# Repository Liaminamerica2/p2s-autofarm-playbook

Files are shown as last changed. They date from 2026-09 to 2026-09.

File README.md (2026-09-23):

# p2s-autofarm

**A self-hosted, hands-off print farm for the Bambu Lab P2S: queueing, server-side slicing, and automatic part ejection, all on your LAN with no cloud required.**

Free to use, fork, and build on for individuals, hobbyists, and small shops (see [License](#license)).

> **Unofficial community guide.** Not affiliated with or endorsed by Bambu Lab, 3D Farmers, or the Bambuddy project. All product names are trademarks of their owners. Anything that moves the toolhead or bends the build plate can damage your printer. Test every change slowly while watching the machine, and use this guide at your own risk.

> **DRAFT:** items marked **TODO** need your own photos, measurements, or a status check before publishing.

---

## What this is

A working setup (and a list of the gotchas) for running a Bambu Lab P2S as an unattended print farm:

- **Bambuddy** for queueing, archiving and print management, self-hosted in Docker
- **Slicer sidecars** (OrcaSlicer and Bambu Studio APIs) for slicing on the server
- **FarmLoop Stage 2** hardware for automatic door opening and plate bending to eject finished parts
- **Everything over local network**: LAN-only mode, Developer Mode, local MQTT

Built and tested on a P2S with AMS 2 Pro. Much of it should carry over to other Bambu printers, but the P2S has quirks (see [Troubleshooting](#troubleshooting)).

## Tested with

| Component | Version |
|---|---|
| Printer | Bambu Lab P2S + AMS 2 Pro |
| Bambuddy | 1.2.5.5 |
| FarmBoard firmware | 2.94 |
| FarmLoop app | 2.72 (states it is tested up to Bambu Studio 2.6) |
| Server | Ubuntu, x86_64, headless, Docker Compose |

> **TODO:** update these to whatever you're running when you publish.

## Architecture

```mermaid
flowchart LR
  D["Desktop slicer<br/>OrcaSlicer / Bambu Studio"] -->|.3mf files| B["Bambuddy<br/>(Docker, port 8001)"]
  B -->|slice requests| S["Sidecars<br/>orca-slicer-api :3003<br/>bambu-studio-api :3001"]
  B -->|LAN mode| P["Bambu P2S"]
  F["FarmBoard<br/>(ESP32-S3)"] -->|watches local MQTT| P
  F -->|drives| M["Door + plate bender"]
```

The FarmBoard does **not** run on custom G-code alone. It connects to the printer's local MQTT broker, watches print progress, and fires its own door and bender motors when it sees timing markers that were embedded in the print file. That is why LAN-only mode and Developer Mode are required, and why processed files must not be renamed or re-saved.

## What's running today

Bambuddy and the OrcaSlicer sidecar are live on a headless Ubuntu box, queueing and archiving prints sent from OrcaSlicer over the LAN. The FarmLoop Stage 2 board is wired into the printer's local MQTT and handles door/bender ejection (bender is unused as it props open the bottom of the p2s printer so i took it out and I just use an engineering plate which releases bellow 30°C) on `FL_S2_`-processed files. The Bambu Studio sidecar and full end-to-end ejection timing are still being confirmed — see [status and troubleshooting](troubleshooting/README.md) if you're building this yourself and want the details.

## Guide contents

For people who want to build this themselves — the full setup, in the order you'd actually do it:

1. **[hardware-setup/](hardware-setup/README.md)** — printer network prep, FarmLoop Stage 2 board assembly, and part-detachment/ejection tuning.
2. **[software-setup/](software-setup/README.md)** — Bambuddy, the slicer sidecars, and the desktop slicer.
3. **[gcode-snippets/](gcode-snippets/README.md)** — known-good G-code fixes injected into prints for the ejection cycle.
4. **[air-quality-and-ventilation/](air-quality-and-ventilation/README.md)** — keeping fumes and particulates out of the room while the farm runs unattended.
5. **[troubleshooting/](troubleshooting/README.md)** — symptom/fix table and the detailed per-component status, for when something doesn't work.

## Alternatives

- **SimplyPrint** offers a FarmLoop AutoPrint integration, but it moved behind its paid Pro plan after its free beta.
- **FarmLoop Pro app** does not work as intended. See [FL_S2_INCIDENT.md](FL_S2_INCIDENT.md).

## Keep out of your fork or PR

Never commit your LAN access code, printer serial number, real IP addresses or Wi-Fi credentials. Also leave out vendor firmware binaries and app-generated files. Use placeholders such as `<PRINTER_IP>` and `<ACCESS_CODE>` in anything you share.

## Contributing

Corrections and other-printer notes are welcome. Open an issue or PR with the printer model, firmware version and what you tested.

## License

[Polyform Small Business License 1.0.0](LICENSE) — free to use, modify, and redistribute (including commercially) for individuals, nonprofits, and small businesses. Larger companies should contact the maintainer about separate terms rather than assume the free grant applies.

## Credits

- [Bambuddy](https://github.com/maziggy/bambuddy) by maziggy -- what a framework!
- 3D Farmers (FarmLoop) documentation and community
- Claude

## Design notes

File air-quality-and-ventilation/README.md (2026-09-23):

# Air quality & ventilation

Keeping print fumes and particulates from ending up in the room while the farm runs unattended.

## Optional: ventilation and placement

- The P2S recirculates air through its built-in HEPA and carbon filter and does **not** vent outside by default.
- Bambu sells an **External Exhaust Fan Kit** (about $20). It needs printer firmware 01.01.01.00 or newer, Bambu Studio 2.4.1.80 or newer, and Bambu Handy 3.11.0 or newer. Ducting and a window adapter are extra, roughly $30 to $50 (4" duct, window panel or foam-board insert, louvered outdoor cap).
- Newer P2S units ship with an updated rear panel that has proper exhaust cutouts. Owners of the original panel could request one.
- **Avoid open-air spaces** like a patio or cabana: temperature swings, dew, dust in the AMS and fans, and filament absorbing moisture.
- Stick to PLA and PETG if the printer lives in a bedroom. Vent ABS and ASA outside.

> **TODO:** add photos of the exhaust kit install, duct routing, and window adapter once installed.

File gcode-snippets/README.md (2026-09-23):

# G-code snippets

Known-good G-code fixes for Bambuddy's per-model start/end G-code injection (**Settings → Workflow → G-code Injection → P2S**), used to keep the FarmLoop Stage 2 board's ejection cycle in sync with the print. See [../software-setup/README.md#4-wire-it-into-bambuddy](../software-setup/README.md#4-wire-it-into-bambuddy) for where this gets configured, and [../hardware-setup/README.md](../hardware-setup/README.md) for the mechanism these markers drive.

> **TODO:** drop your actual working injection files in this folder (e.g. `end-gcode-p2s.gcode`) once finalized, and list them below. The notes here are what's been learned so far — the vendor tools regenerate raw G-code that needs the same fixes reapplied each time.

See **[GCODE-HOWTO.md](GCODE-HOWTO.md)** for the reverse-engineered mechanism behind the FarmBoard trigger sequence (MQTT sentinels via `M104 Sn`, tap/press gestures, sweep and cooldown blocks) — read this before hand-writing an injection block instead of relying on the FarmLoop app's output.

## Known-good notes

- On the P2S, `M106 P2` is the **auxiliary** fan and `M106 P3` is the **exhaust** fan. Generated code that fires the wrong one for cooldown needs `P2` swapped for `P3` in both the on and off lines.
- The stock Machine End G-code already runs a two-stage cooldown (aux fan first, then an exhaust fan gated on chamber temperature) **before** any block you add. If the door seems to wait forever, look there first — it's usually not your injected block.
- If the sweep or push runs too high and misses parts, measure the vertical gap between the nozzle tip and the pusher's contact face with the printer idle. Generated math may assume they're coplanar.
- Bambuddy inserts your start snippet **after** the printer's own homing/heat/prime, and your end snippet **after** the printer's entire stock end sequence (which ends in `M18`, steppers off). So: no `G28` needed at the top of a start snippet, and an `M17` is needed at the top of an end snippet before any `G1 Z` move. See [GCODE-HOWTO.md §10](GCODE-HOWTO.md#10-how-bambuddy-actually-inserts-these-snippets) for the full mechanism, verified against Bambuddy source.
- Injection failure is silent — a bad snippet just falls back to the un-injected file with a server-side log line, nothing visible on the printer.

## Files in this folder

- **[`start-gcode-p2s.gcode`](start-gcode-p2s.gcode)** — start-of-print injection: homes, then arms the FarmBoard (RESET sentinel + 4-tap gesture) and fires TRIGGER 0.
- **[`end-gcode-p2s.gcode`](end-gcode-p2s.gcode)** — end-of-print injection ("Option A" in [GCODE-HOWTO.md §9](GCODE-HOWTO.md#9-options-for-the-ejection-block)): cools with the door closed, gates the door open on bed temperature, sweeps the plate with the pusher, closes the door. Bender/safety stages are skipped — that hardware isn't in this build.
- **The test plan** — the header of `end-gcode-p2s.gcode` is an 8-step, one-variable-at-a-time campaign (cooling → plate release / is the bender needed → door → pusher height on an empty plate → sweep on a real part → full cycle → the print after → first unattended run), each step naming the parameter it fills in. Test snippets for the steps that are easy to get wrong by hand:
  - [`end-gcode-test-door.gcode`](end-gcode-test-door.gcode) — step 3: open, wait, close; nothing else.
  - [`end-gcode-test-sweep-height.gcode`](end-gcode-test-sweep-height.gcode) — step 4b/4c: one sweep at a fixed height on an empty plate, run per height from Z20 down; finds `SWEEP_MIN` without ever using the placeholder.
- **[`end-gcode-test-m190.gcode`](end-gcode-test-m190.gcode)** — step 1, diagnostic only. Swap it in for one run to learn whether `M190 S28` really blocks until the bed cools; the readout is the part fan spinning up and a 30 mm toolhead jog after each wait, plus the bed temperature when Finished appears (no door, no taps, no FarmBoard involved — and no "logo lamp", the P2S doesn't have one). Procedure and result table in [GCODE-HOWTO.md §11](GCODE-HOWTO.md#11-first-live-run-2026-09-20-and-the-m190-test). **Do not use `M190 R` on this printer** — it raised a bed-over-limit error and clamped the bed target up.
- The tunable values (release temperature, dwell padding, the `{max_layer_z} − 10` sweep height and its 12 mm minimum) are in the comment header at the top of `end-gcode-p2s.gcode` — read that before your first run.

**Status (2026-09-22):** every non-stock line in both snippets has been checked against the P2S stock templates, the community G-code atlas, the FarmLoop vendor docs and forum reports — the table is [GCODE-HOWTO.md §12](GCODE-HOWTO.md#12-line-by-line-verification-2026-09-22). Door open/close and the sentinels work on this board; the sweep height is per-model; cooldown now recirculates through the filter instead of venting. Still unconfirmed on this printer: the `M190 S` finish temperature (test snippet running), pusher contact at the new sweep height, and how long filter-mode cooldown takes.

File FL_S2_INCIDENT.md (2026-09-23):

# Incident report: the FarmLoop Pro app's G-code idles a hot printer for hours

**TLDR:** I bought the FarmLoop Stage 2 kit for hands-off printing on my Bambu Lab P2S. The G-code the FarmLoop Pro app (v2.72) produced for me contains a two-hour "natural cooldown" wait in the **start** of every loop, before the print begins, with the heaters on and the fans off. I saw it on two different models. On the first, the printer stalled and I ran it for about 30 minutes before cutting power.

This repo exists because software sold for *unattended* printing has to produce G-code that is safe when nobody is watching, and I could not rely on that.

> **DRAFT:** items marked **TODO** need your own confirmation, screenshots or files before publishing.

---

## What I am and am not claiming

**Claiming (verified from the files):**

- The processed files contain the block shown below, in the start sequence, once per loop.
- The block's own comment says it is meant to run before the door opens, which is post-print logic.
- The heaters are left on and the fans are switched off while it runs.
- This is what the app gave me on two different models. 

**Not claiming:**

- That the vendor intended this, or knew about it.
- That every file, printer model or app version has the problem. I only tested a P2S with app v2.72.
- That my printer was permanently damaged.

The app itself tells users they use it at their own risk. This report is about what that risk looked like in practice.

---

## Timeline

Dates are approximate.

| When | What happened |
|---|---|
| Aug 2026 | Bought and installed the FarmLoop Stage 2 hardware for the P2S. |
| Sep 6 | Ran the first processed file (File A). About 5 minutes in, after the AMS filament step, the printer stopped making progress. I let it run about 30 minutes, then cut power and inspected the machine. |
| Sep 7–8 | Unzipped File A and a plain slice of the same model and diffed them. Found the cooldown block. |
| Sep 19 | Processed a new, unrelated model (File B) in the app. **The same block is present.** I did not run it. |

---

## This is the app's default output

Both files came straight out of the app's **Process Gcode** step. I did not edit them, rename them or re-save them in a slicer.

Settings visible in File B's G-code:

| Setting | Value in the file |
|---|---|
| Printer | P2S |
| Detachment | Push Mode (the only mode available on the P2S) |
| Loops | 2 |
| Bed temperature | 55 °C |
| Post-print cooldown | Temperature-based, target 26 °C |

Screenshots of the **Detachment Tuning** page for File B, taken before clicking Process Gcode, confirm these match what was on screen — Push Mode, 55 °C bed, and a temperature-based cooldown targeting 26 °C:

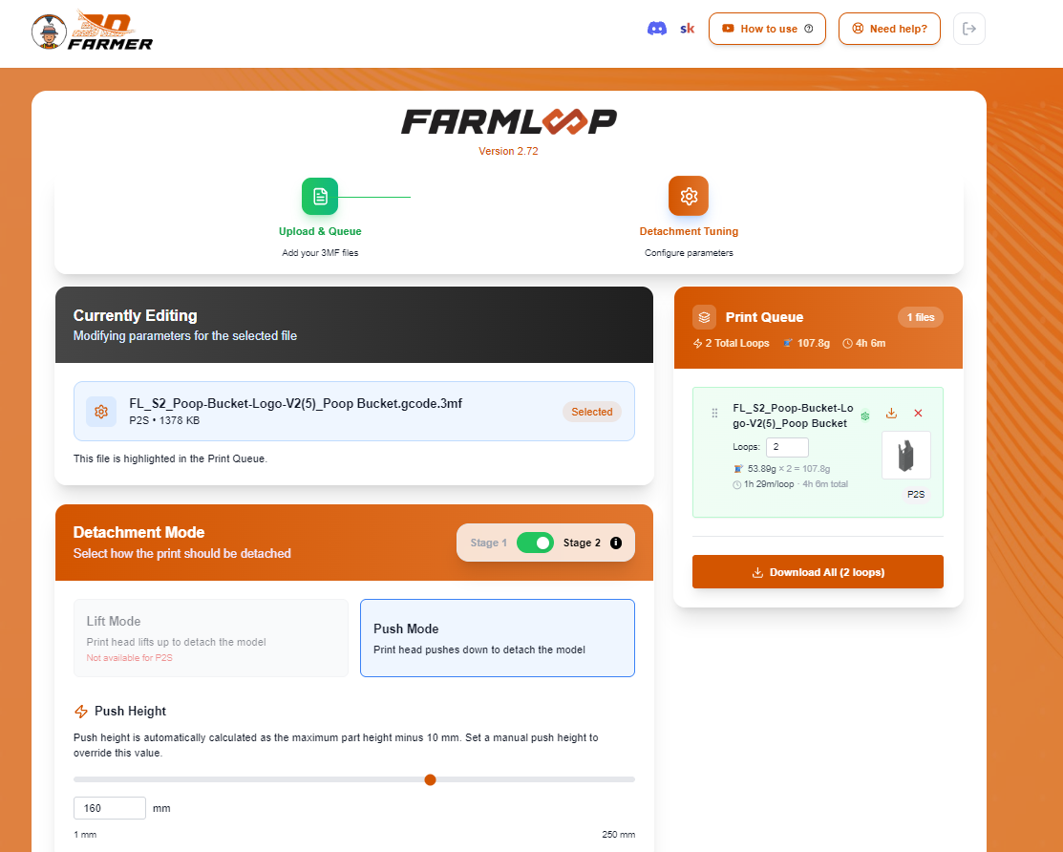
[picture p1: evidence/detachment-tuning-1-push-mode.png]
Detachment Mode and Push Height settings in the FarmLoop app


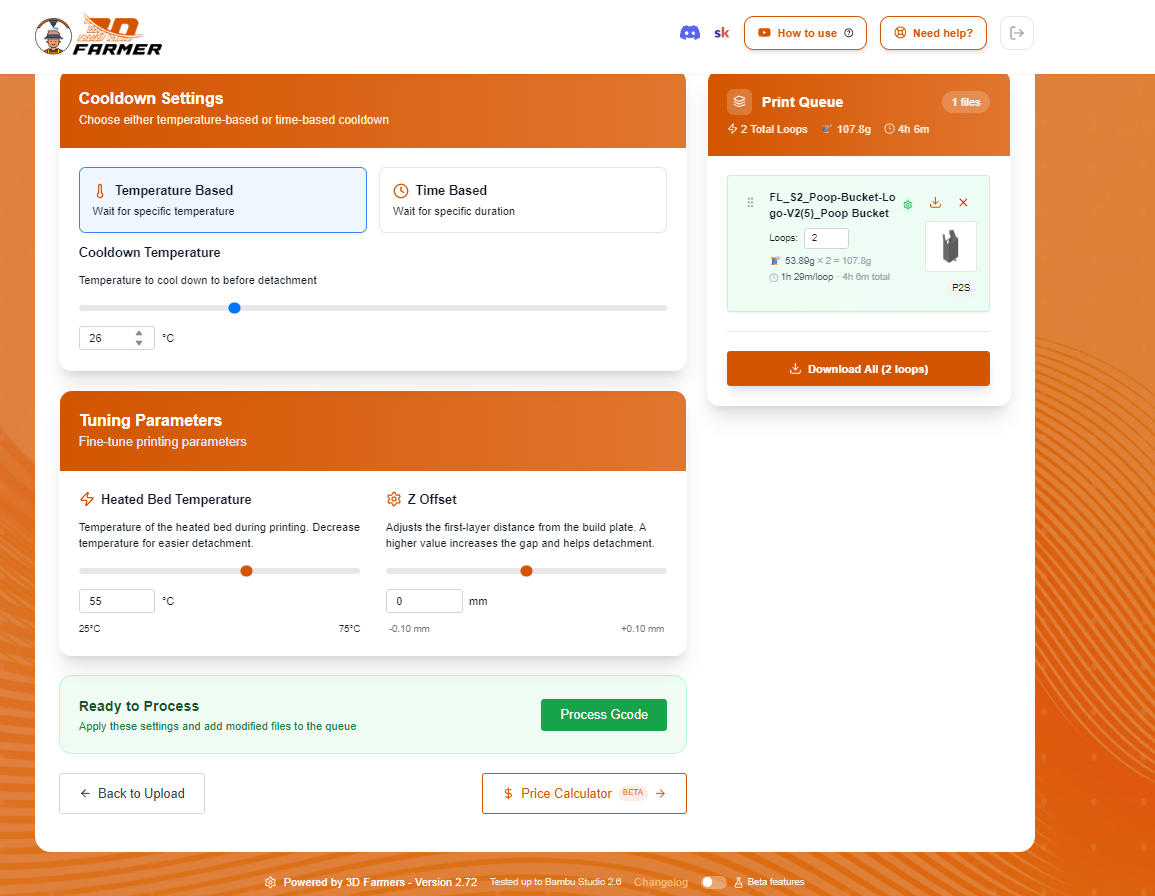
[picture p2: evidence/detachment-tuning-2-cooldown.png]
Cooldown Settings and Tuning Parameters in the FarmLoop app


**Beta features were off** (see the toggle in the app's footer, bottom right of the second screenshot). Nothing here came from an experimental or opt-in feature — Push Mode, temperature-based cooldown, and the bed/Z-offset tuning are all part of the app's regular, out-of-beta feature set. This is the G-code the app's stable, promised functionality produces.

---

## What the G-code does

Excerpt from the processed file. The repeated dwell lines are elided:

```gcode
; ================ FL NATURAL COOLDOWN ================
; Hold in the closed chamber for 120 min before the door opens.
; Fans off so the part cools evenly instead of from one side — ASA, ABS
; and PC warp and split when cooled fast while still stuck to the plate.
M106 S0          ; part cooling fan off
M106 P2 S0       ; auxiliary fan off
M106 P3 S0       ; chamber fan off
G4 S30
G4 S30
... (240 x G4 S30 in total)
; ================ FL NATURAL COOLDOWN END (120 min) ================
M104 S220
```

`G4 S30` is a 30-second dwell. 240 of them is 7,200 seconds, or 2 hours.

| | File A | File B |
|---|---|---|
| Loops | 2 | 2 |
| Dwells per loop | 240 x `G4 S30` (2 h) | 240 x `G4 S30` (2 h) |
| Total wait before printing | About 4 h | About 4 h |
| Fans during the wait | Off | Off |
| What follows the block | `M104 S220` (heat to print temperature) | `M104 S220` |

### Why this is a defect

1. **It is in the wrong place.** The comment describes a post-print hold ("before the door opens"), but the block runs before printing starts.
2. **The heaters stay on.** In File B, the start sequence sets the bed to 55 °C and holds the nozzle at a 140 °C target before the block. There is no heater-off command between those lines and the end of the block, so both stay on for the full two hours. The nozzle only goes to 220 °C afterwards.
3. **The fans are switched off.** The block turns off the part-cooling, auxiliary and exhaust fans. I don't know how the firmware manages the hotend's own cooling.
4. **It doesn't look like my cooldown setting.** File B also has a separate post-print cooldown (`M190 S26`, repeated 62 times per loop), which looks like the temperature-based option. So the 120-minute block does not appear to be what I selected. This is an inference from the file. **TODO:** check it against your screenshots.
5. **It looks like a freeze.** On the printer's screen the machine appears to hang right after the filament step, then sits there. That is what I saw.

---

## What G-code like this can do to a printer

I'll separate what I saw from what could plausibly happen. I have not tested the second list on my own machine, and most of it comes down to general 3D-printer behavior rather than P2S-specific knowledge.

### What I saw

- The printer stalled early in the job and made no progress for about 30 minutes.
- The nozzle and bed were hot the whole time.
- I heard a motor-stalling noise and noticed a bad smell. **TODO:** confirm these details. I don't know which command caused the noise, and I haven't isolated it.

### What could plausibly happen

1. **Hot heaters running unattended for hours.** A printer that looks idle but has a hot bed and nozzle is a fire and safety concern. Firmware protections are designed to catch heater faults, such as a heater running away from its target. As far as I know, they are not designed to override a job that deliberately keeps a heater on.
2. **Filament degrading inside the hot nozzle.** Filament left sitting in a heated hotend for a long time can ooze, degrade or carbonize, and that can lead to clogs and a stringy or under-extruded start. A burning smell is consistent with this, but I can't prove that was its source.
3. **Extra heat in a closed chamber.** With the bed hot and the fans off, a closed chamber will warm up more than it would at true idle, for hours. Anything else heat-sensitive nearby gets that extra load too.
4. **Motors and axes driven into stops.** Automation that talks to external hardware often moves an axis to a fixed position to press a switch. If a move like that is mistimed, or the hardware isn't where the code expects, the axis can stall. That risks skipped steps, wear on the motor, leadscrew or bed carriage, and a Z axis that is no longer where the printer thinks it is. I don't know whether that's what my printer's noise was.
5. **Mechanisms moving at the wrong time.** The FarmBoard's door and bender run on timing markers in the file. If the wait shifts the timing relative to what the mechanism expects, it can move while the toolhead or the plate is not where it should be, which risks a collision.
6. **Bad reactions to a "frozen" printer.** A machine that looks stuck invites you to cancel the job or cycle the power. Cutting power while the nozzle is hot and full of filament is not good for the hotend.
7. **Wasted time and filament, and false confidence.** A four-hour delay that shows up before anything prints defeats the point of automating, and it makes you trust the next unattended run less, or trust it too much.

### Why unattended automation raises the stakes

The whole selling point of a print-farm add-on is that you walk away. A bug that would be a nuisance while you're standing next to the printer becomes a safety problem when nobody is there. That makes the G-code the most important part of the product, and it's the part you can't easily inspect unless you know to look.

---

## How to check your own files before running them

`.3mf` files are zip archives. Extract the G-code and look for long runs of dwells:

```bash
mkdir raw fl
unzip -q raw_slice.gcode.3mf -d raw           # plain slice from your slicer
unzip -q FL_S2_slice.gcode.3mf -d fl          # file from the FarmLoop app
diff raw/Metadata/plate_1.gcode fl/Metadata/plate_1.gcode | less
grep -c '^G4 S30' fl/Metadata/plate_1.gcode   # hundreds is a red flag
grep -n 'NATURAL COOLDOWN' fl/Metadata/plate_1.gcode
```

Then, for any new file:

- Watch the first several minutes with a hand near the power switch.
- Don't leave the heaters on unattended until you've seen the file behave.
- If the printer sits idle after the filament step, don't assume it's slow. Look at the G-code.

---

## Evidence

Both File B archives are now in [`evidence/`](evidence/) — the plain slice and the app-processed output, unmodified:

- [`evidence/Poop-Bucket-Logo-V2(5)_Poop Bucket.gcode.3mf`](evidence/Poop-Bucket-Logo-V2(5)_Poop%20Bucket.gcode.3mf) — plain slice, no FarmLoop processing
- [`evidence/FL_S2_Poop-Bucket-Logo-V2(5)_Poop Bucket.gcode.3mf`](evidence/FL_S2_Poop-Bucket-Logo-V2(5)_Poop%20Bucket.gcode.3mf) — same model, run through the app's Process Gcode step

I re-extracted and re-checked every figure below directly against these two files: checksums, the cooldown block's exact line numbers, and the dwell count (`grep -c '^G4 S30'` on the processed file returns **480** — 240 per loop × 2 loops, matching the table below). All confirmed, not estimated.

File B, as processed:

| Item | Value |
|---|---|
| Archive | `FL_S2_Poop-Bucket-Logo-V2_5__Poop_Bucket_gcode.3mf` (underscores may replace spaces and parentheses from the app's file name) |
| SHA-256 (archive) | `e75259043c768a2f4a3a3804839996c645a31194f73ebb2dc0f124c368ea9f68` ✓ verified |
| SHA-256 (`Metadata/plate_1.gcode`) | `b14a1df88863ba81b4c43f103122e305b58392ef7717a3ff77faa0b004669716` ✓ verified |
| Loop 1 block | Lines 723–970 ✓ verified |
| Loop 2 block | Lines 210852–211099 ✓ verified |

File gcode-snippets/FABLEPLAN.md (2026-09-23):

# Plan: G-code options for emptying the P2S after a print

## Context

The FarmLoop app's generated G-code is not trustworthy (see `FL_S2_INCIDENT.md`), so the ejection cycle
needs to be hand-written and injected via Bambuddy (or the slicer's Machine End G-code). The
mechanism is now documented in `gcode-snippets/GCODE-HOWTO.md`. This build differs from what the
app assumes:

- **Engineering plate**: parts self-release once the bed drops below ~30 °C. No bending needed.
- **Bender removed** (it propped the chamber open). Only the FarmBoard **door** and the toolhead
  **pusher** remain.
- FarmBoard runs Digital (MQTT) mode, but the user wants **both** the `M104 Sn` sentinels and the
  Z tap gestures kept, like FarmLoop does, so the cycle works even if MQTT drops.
- Decisions taken: **cool with the door closed first**, gate release on **bed temp (`M190`) plus a
  short buffer**, sweep with the **FarmLoop pusher out the front door**.

Deliverable: the option set written up (so the user can pick/mix), plus the recommended option
drafted as two snippet files ready to paste into Bambuddy.

## Options (all to be documented; only A gets drafted as a file)

| | Option | Order of events | Pros | Cons / risks |
|---|---|---|---|---|
| **A (recommended)** | Cool-closed, then open, sweep, close | print end → part fan off, aux+exhaust on → `M190 S<release>` → buffer dwell → **T1** door open → sweep (2 heights, 2 speeds) → **T3** door close → tail | Parts release before anything moves; chamber heat stays in the box; no bender/safety stages | Slower than B; needs `M190` to block on *cooling* on Bambu firmware (verify) |
| B | FarmLoop order: open first, cool with door open | print end → **T1** door open + fan → `M190` → sweep → **T3** close | Fastest cooldown | Dumps chamber heat and fumes into the room; door open for the whole wait |
| C | Sentinel-only (no Z taps) | Same as A minus every `G1 Z243/Z255` block | Shortest, no Z-axis hammering, no `Z20`/`Z220` park oddities | Dead if MQTT drops (user chose against this, keep as a documented fallback) |
| D | No FarmBoard | Door left open/removed; `M190` → sweep → park | Zero dependency on the board | Chamber open permanently; PLA/PETG only; fumes |
| E | Material-dependent A/B | Two end blocks toggled per queue item in Bambuddy | Best of A and B | Two snippets to maintain |

Sweep sub-options (documented, A uses E1+E2):
- **E1 Dual-height rake**: first pass at `SWEEP_Z_HIGH` (catches tall parts before the low pass can
  topple them), second at `SWEEP_Z_LOW` (short parts). Both use FarmLoop's X-stepped, Y front↔back rake.
- **E2 Two speeds**: slow (`F3000`) pass first, fast (`F12000`) pass second — FarmLoop's pattern, keep.
- E3 Nudge pass: one slow pass at low Z *before* the real sweep, to break any parts still stuck.
- E4 Perimeter-first: clear the four edges toward the front before the central rake (for plates
  packed to the edges).

Release-gate sub-options: `M190 S<t>` + `G4 S<buffer>` (chosen); fixed time only; `M190` + nudge pass.

## Recommended design (Option A) — what the end snippet does

```
;--- 1. heaters off, cool with door CLOSED
M106 S0            ; part fan off
M106 P2 S255       ; aux fan on
M106 P3 S255       ; exhaust fan on
M140 S0
M104 S0
M190 S<RELEASE_TEMP>   ; e.g. 28 — VERIFY it blocks on cool-down (else use R)
G4 S<RELEASE_BUFFER>   ; e.g. 120 — plate/part interface lags the bed sensor
;--- 2. T1: door open (+ FarmBoard fan)
M104 S2
<TRIGGER 1 long-press taps, from GCODE-HOWTO §6a>
G4 S<DOOR_OPEN_WAIT>   ; ~8 s per FL comment, pad to 12
;--- 3. sweep (dual height, dual speed, from GCODE-HOWTO §6d pattern)
G1 Z<SWEEP_Z_HIGH> F10000 ; = pusher_bottom_height + PUSHER_OFFSET
<rake @ F3000>
G1 Z<SWEEP_Z_LOW>  F10000
<rake @ F12000>
G1 X65 Y245 F12000 ; safe corner
G1 Y265 F3000      ; park rear
;--- 4. T3: door close  (T2 bend and S4 safety SKIPPED — bender removed)
M104 S5
<TRIGGER 3 long-press taps, from GCODE-HOWTO §6e>
;--- 5. tail
M106 S0 / M106 P2 S0 / M106 P3 S0, M400, M17 S / M17 Z0.4 / M400 P100 / M17 R, M17 X0.8 Y0.8 Z0.5
```

Parameters go in a comment header at the top of the file (`RELEASE_TEMP`, `RELEASE_BUFFER`,
`DOOR_OPEN_WAIT`, `PUSHER_OFFSET`, `SWEEP_Z_HIGH`, `SWEEP_Z_LOW`) with the values substituted inline —
plain G-code, no templating.

Start snippet = GCODE-HOWTO §3 verbatim (G28, `M104 S1`, 4-tap reset, TRIGGER 0), with the odd
`G1 Z20` final release changed to `G1 Z243` and flagged for a hardware check.

## Files

- **Create** `gcode-snippets/end-gcode-p2s.gcode` — Option A as above.
- **Create** `gcode-snippets/start-gcode-p2s.gcode` — RESET + TRIGGER 0.
- **Edit** `gcode-snippets/GCODE-HOWTO.md` — add `## 9. Options for the ejection block`: the table
  above, sweep/release sub-options, and the two open questions below.
- **Edit** `gcode-snippets/README.md` — fill "Files in this folder" with the two snippets and what
  each parameter means.

## Open questions to settle during implementation / first test

1. **Where Bambuddy inserts the end block.** If it appends *after* the slicer's Machine End G-code,
   the stock tail has already run `M18` (steppers off) and the 6-min air-purification waits. The
   snippet must then start with `M17` and either trust retained position or `G28 X Y` (not a full
   `G28`: Z-homing probes the bed and parts are still on it). Alternative: put the block in the
   OrcaSlicer printer profile's Machine End G-code *before* the stock tail — FL's file does exactly
   this (it deletes the stock sound/purification/`M18` and puts its tail last). Decide after checking
   Bambuddy's injection point once.
2. **Does the FarmBoard accept T3 (`S5`) without seeing T2 (`S3`) and Safety (`S4`) first?** Unknown.
   If it insists on the sequence, send `M104 S3` + `M104 S4` with no taps and no bend wait as a
   no-op ordering shim (bender absent → nothing physically happens).

## Verification

1. Extract-and-diff sanity: build a 3mf with the snippets, `unzip`, `grep -c '^G4 S30'` must be 0,
   `grep -n 'M104 S[1-5]' plate_1.gcode` shows S1 near the start and S2, S5 only after the last
   layer.
2. Dry run, heaters off: send a tiny 1-layer test print. Watch: reset taps at start, door stays
   closed until bed < `RELEASE_TEMP`, door opens, both sweep passes run at the expected heights,
   door closes, printer parks. Hand on the power switch.
3. Sweep-height check with a real part: measure nozzle-tip-to-pusher-face gap with the printer idle
   (per `hardware-setup/README.md`) and confirm `SWEEP_Z_LOW` clears the plate but hits parts ≥ 5 mm tall.
4. Only after 2–3 pass: first unattended run, then update the `TODO: confirm` rows in
   `troubleshooting/README.md` (door opening, push sweep height, cooldown timing).

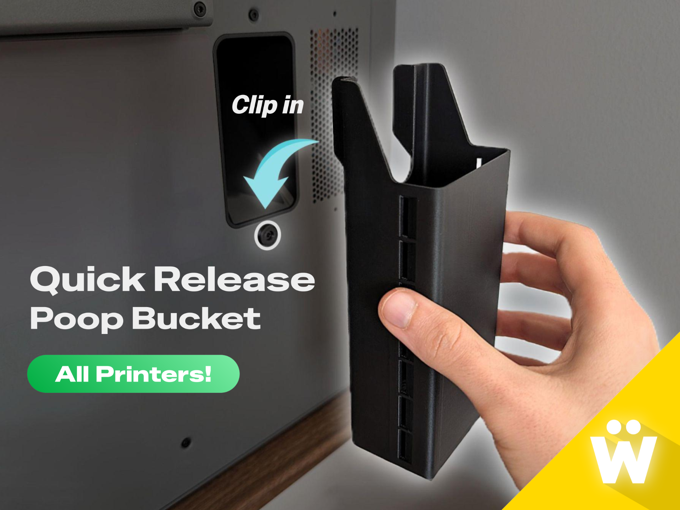
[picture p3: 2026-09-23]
evidence/_fl/Auxiliaries/.thumbnails/thumbnail_middle.png

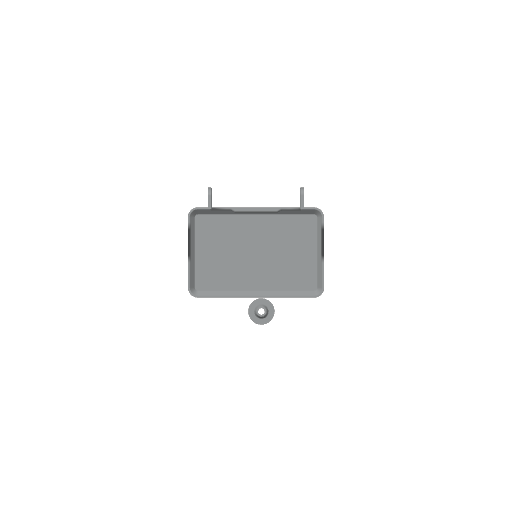
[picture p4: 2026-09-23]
evidence/_fl/Metadata/top_1.png

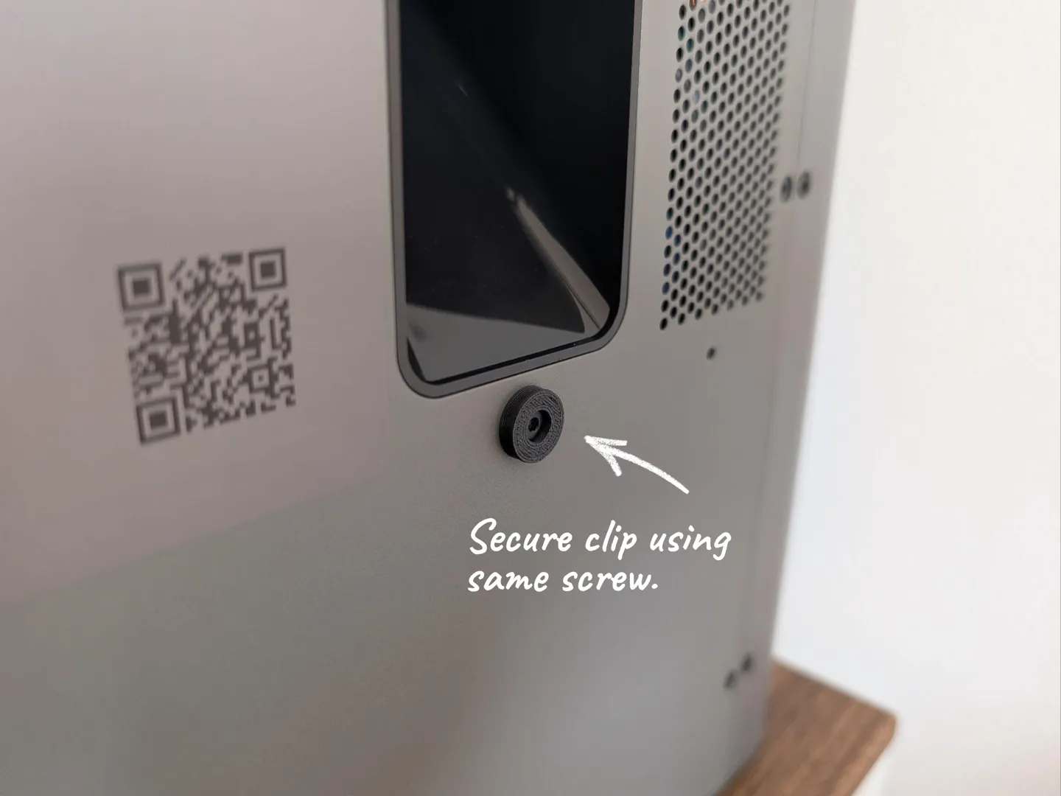
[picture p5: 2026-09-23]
evidence/_raw/Auxiliaries/Model Pictures/Model Pictures and More - Landscape.4.webp

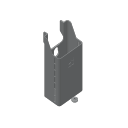
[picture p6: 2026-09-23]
evidence/_fl/Metadata/plate_1_small.png

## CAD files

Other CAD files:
evidence/FL_S2_Poop-Bucket-Logo-V2(5)_Poop Bucket.gcode_single_loop.3mf
evidence/FL_S2_Poop-Bucket-Logo-V2(5)_Poop Bucket.gcode.3mf
evidence/Poop-Bucket-Logo-V2(5)_Poop Bucket.gcode.3mf

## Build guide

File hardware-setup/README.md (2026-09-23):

# Hardware setup

Getting the P2S, AMS, and FarmLoop Stage 2 kit physically assembled, networked, and tuned so parts actually get ejected. For the server-side software (Bambuddy, slicer sidecars), see [../software-setup/README.md](../software-setup/README.md). For the G-code injected into prints, see [../gcode-snippets/README.md](../gcode-snippets/README.md).

## Bill of materials — hardware

| Item | Notes |
|---|---|
| Bambu Lab P2S | With AMS 2 Pro |
| FarmLoop Stage 2 kit | FarmBoard, door, bender and pusher attachment |
| Engineering build plate | Fixed part-detachment problems in this setup |
| Always-on Linux box | Any x86_64 machine that can run Docker |
| Storage for the printer | SD card and/or large USB stick (see [Prepare the printer](#1-prepare-the-printer)) |

## 1. Prepare the printerhttps://marketplace.visualstudio.com/items?itemName=appliedengdesign.vscode-gcode-syntax

1. Update the printer firmware and slicer to current versions.
2. Turn on **LAN-only mode** and **Developer Mode**. Local MQTT is only exposed when both are on.
3. Write down three values. You will need them for both Bambuddy and the FarmBoard:
   - Printer IP (Wi-Fi settings on the printer)
   - LAN access code (8 digits, network settings)
   - Serial number (device settings)
4. **The access code regenerates when you toggle LAN-only or Developer Mode.** Re-read it after any change.
5. Insert storage. The P2S needs it for file transfer and thumbnails, and "store on external storage" is now a toggle on the printer itself rather than in the slicer. If you record video or timelapse, use a large-capacity stick formatted in the printer, because a full USB stick has been reported to freeze prints mid-job.

> Give the printer a DHCP reservation so its IP never changes. 

## 2. Set up the FarmLoop Stage 2 board

1. Assemble the kit following the vendor's instructions. TODO: DETERMINE IF THE BENDER IS REQUIRED BECAUSE WE HAVE THE ENGINEERING PLATE
2. Put the FarmBoard in **OTA mode** and open `http://farmloop.local`.
3. In the **Printer Connection** card, enter your Wi-Fi SSID and password, the printer IP, the LAN access code and the serial number.
4. Tick **Enable MQTT auto-trigger**, save, and exit OTA mode.
5. Read the LED after reboot:

| LED pattern | Meaning |
|---|---|
| 5 slow + 10 fast blinks | Wi-Fi and MQTT both connected |
| 2 long blinks | Wi-Fi failed: check SSID and password |
| 4 long blinks | MQTT failed: check printer IP, access code and LAN-only mode |

While Digital mode is connected, the board's limit switch is disabled. Turn Digital mode off (or take the printer off the network) if you need it for testing.

> **No-software fallback:** the board also has a Mechanical mode driven by button gestures (close door, open door + fan, start bending, and so on). It works with no app, account or Wi-Fi, but you have to be there to tap through each stage. See the vendor's docs for the gesture table.

## 3. Prepare files for ejection

1. Process your sliced file in the FarmLoop app. Output files are prefixed with **`FL_S2_`** and carry the embedded markers.
2. **Do not rename or re-save** the processed file (not in Bambu Studio, not in a file browser). Doing so can strip the markers and the cycle won't fire. Re-process through the app instead.
3. On the P2S, **Push Mode is the only detachment option.** Lift Mode is marked "Not available for P2S" in the app. Push height defaults to max part height minus 10 mm and can be overridden.
4. Tuning that helps detachment: a lower bed temperature and a slightly higher first-layer Z offset. An engineering plate made the biggest difference here.
5. If the sweep or push runs too high and misses parts, measure the vertical gap between the nozzle tip and the pusher's contact face with the printer idle. Generated math may assume they're coplanar.

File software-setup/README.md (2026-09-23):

# Software setup

The server-side stack: Bambuddy, the slicer sidecars, and the desktop slicer. For physically setting up the printer and the FarmLoop board, see [../hardware-setup/README.md](../hardware-setup/README.md). For the actual G-code injected into prints, see [../gcode-snippets/README.md](../gcode-snippets/README.md).

## Bill of materials — software

| Item | Purpose |
|---|---|
| [Bambuddy](https://github.com/maziggy/bambuddy) | Self-hosted print manager (queue, archive, G-code injection) |
| `orca-slicer-api` / `bambu-studio-api` | Server-side slicing sidecars, shipped in Bambuddy's `slicer-api/` folder |
| OrcaSlicer or Bambu Studio | Desktop slicing (the slicer itself needs a GUI) |
| FarmLoop app | Processes files and embeds the markers the FarmBoard listens for |

## 1. Run Bambuddy

On the server:

```bash
git clone https://github.com/maziggy/bambuddy.git
cd bambuddy
docker compose up -d
```

Follow the upstream README for the exact compose file and options. The UI comes up on port **8001** (`http://<SERVER_IP>:8001`).

- If you can't reach it from another device, check the server's firewall first.
- In the UI, add the printer using its IP, access code and serial number (see [../hardware-setup/README.md#1-prepare-the-printer](../hardware-setup/README.md#1-prepare-the-printer)).
- Bambuddy offers an optional Bambu Cloud token sync. Skip it if you want to stay fully local.

## 2. Add the slicer sidecars

The sidecars are pre-built `linux/amd64` images, so no local build is needed. They live in a **subfolder** of the Bambuddy repo:

```bash
cd bambuddy/slicer-api
cp .env.example .env            # optional: change ports or pin SIDECAR_TAG
docker compose up -d            # OrcaSlicer sidecar only
# or
docker compose --profile bambu up -d   # both sidecars
```

Then check health and point Bambuddy at them:

```bash
curl http://localhost:3003/health
```

In Bambuddy go to **Settings → Slicer** and set the sidecar URL to `http://<SERVER_IP>:3003` (OrcaSlicer) and `http://<SERVER_IP>:3001` (Bambu Studio).

Things to know:

- Ports **3000 and 3002** are reserved by Bambuddy's virtual-printer feature. That's why the OrcaSlicer sidecar publishes on 3003.
- If you use the `bambu` profile, you must pass `--profile bambu` on **every** compose command (pull, up, down), or that service is silently skipped.
- `docker exec -it bambuddy sh` puts you in the main Bambuddy container, not a sidecar. Use `orca-slicer-api` or `bambu-studio-api` as the container name for those.

## 3. Choose a desktop slicer

- **OrcaSlicer** is the better default here: native P2S profiles, open source, and it works well with Bambuddy's archiving.
- **Bambu Studio** gets fresher official profiles. Use **"Send with External storage"** rather than the plain Print button, or Bambuddy's archiving is bypassed.
- Bambuddy can act as a **virtual printer**, so your slicer can send files straight to it.

## 4. Wire it into Bambuddy

Bambuddy supports per-model start and end G-code snippets that can be toggled per queue item. This is where a fully local pipeline gets tricky, because the FarmBoard expects the processed file's markers to survive intact.

Injection happens **server-side in Python at print-dispatch time**, editing a temp copy of the `.gcode.3mf` — the original file is never touched. Your start snippet (Settings → Workflow → G-code Injection → P2S → start_gcode) is spliced in **after** the printer's own homing/heat/prime already ran; your end snippet is spliced in **after** the printer's entire stock end sequence, including its final `M18` (steppers off). Both of those facts drove real fixes in this repo's own snippet files — see [../gcode-snippets/GCODE-HOWTO.md#10-how-bambuddy-actually-inserts-these-snippets](../gcode-snippets/GCODE-HOWTO.md#10-how-bambuddy-actually-inserts-these-snippets) for the full mechanism (verified against Bambuddy source, commit `9e9c08b`), including why the start snippet has no `G28` and the end snippet opens with `M17`.

One more thing worth knowing: **injection failure is silent** — an exception or bad snippet just falls back to printing the original, un-injected file, with only a server-side log line to tell you. If the ejection cycle doesn't fire, check Bambuddy's logs before assuming the G-code itself is wrong.

The actual snippet files (fan channel swap, cooldown timing, sweep height math) live in [../gcode-snippets/README.md](../gcode-snippets/README.md) — read that before writing your own injection block.

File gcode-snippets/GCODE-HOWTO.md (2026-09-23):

# G-code how-to: the FarmBoard ejection cycle

Reverse-engineered by diffing a plain slice against the same model run through
the FarmLoop app's Process Gcode step. Sources:

- Plain slice: [`../evidence/Poop-Bucket-Logo-V2(5)_Poop Bucket.gcode.3mf`](../evidence/Poop-Bucket-Logo-V2%285%29_Poop%20Bucket.gcode.3mf)
- Processed, single loop: [`../evidence/FL_S2_Poop-Bucket-Logo-V2(5)_Poop Bucket.gcode_single_loop.3mf`](../evidence/FL_S2_Poop-Bucket-Logo-V2%285%29_Poop%20Bucket.gcode_single_loop.3mf)

Goal: document the mechanism well enough to hand-write an equivalent
Bambuddy start/end G-code injection block (see
[../software-setup/README.md#4-wire-it-into-bambuddy](../software-setup/README.md#4-wire-it-into-bambuddy))
instead of depending on the FarmLoop app, whose output has at least one
serious placement bug — see [../FL_S2_INCIDENT.md](../FL_S2_INCIDENT.md) before
copying anything below verbatim.

> **DRAFT:** built from one model, one app version (2.72), FarmBoard firmware
> 2.94, P2S + Push Mode. Re-diff against your own files before trusting exact
> values. Comments in brackets are this doc's own notes, not from the source file.

---

## 1. The mechanism, in short

The FarmBoard doesn't parse G-code for meaning. It watches the printer's
**local MQTT** state — specifically `nozzle_target_temper`, set by `M104 Sn` —
for a small set of out-of-band values, and reacts to *when* that value shows
up and how long it stays. Two primitives do all the work:

1. **Sentinel values** — `M104 S<n>` where `n` is 1–5. These are never real
   print temperatures; they're a signal piggybacked on a command the firmware
   already reports over MQTT. Each value arms the next FarmBoard stage.
2. **Switch taps** — `G1 Z<height> F<feed>` moves that press/release a
   physical limit switch, because the bed/gantry position doubles as an input
   to the FarmBoard. `Z255` = pressed, `Z243` = released, `Z220` = fully
   retracted/parked. Tap *pattern* (count, duration, spacing) selects which
   gesture fires — this mirrors the vendor's documented Mechanical-mode
   gesture table (see [../hardware-setup/README.md](../hardware-setup/README.md)),
   just driven by G-code instead of a finger.

Sentinel table, in the order they appear in the file:

| Value | Name | Stage armed |
|---|---|---|
| `M104 S1` | RESET | Home the mechanism, arm MQTT auto-trigger |
| `M104 S2` | T1 | Fan on + door open (post-print) |
| `M104 S3` | T2 | Start bending |
| `M104 S4` | Safety | Run safety check |
| `M104 S5` | T3 | Final door close |

Every sentinel is followed almost immediately by the tap sequence for that
stage, then a `G4` dwell long enough for the physical mechanism to finish
before the next G-code line runs.

---

## 2. Tap/press primitives

| Command | Meaning |
|---|---|
| `G1 Z255 F<feed>` | Press the switch |
| `G1 Z243 F<feed>` | Release the switch (holding position) |
| `G1 Z220 F<feed>` | Release and fully retract (park) |
| `G4 P<ms>` | Dwell in milliseconds — used for short, precise gaps |
| `G4 S<sec>` | Dwell in seconds — used for long waits |
| `M400` | Wait for planner moves to finish before the next dwell starts, so the dwell timing is accurate |

Feed rates used: `F6000` (fast, first tap of a burst), `F3000` (normal
tap/release), `F1000` (slow presses inside a multi-tap gesture, e.g. triple
tap). Gesture identity seems to come from **tap count + hold duration**, not
feed rate — feed rate mostly just controls how crisp the press looks.

---

## 3. Start-of-print: RESET + TRIGGER 0

Inserted right after the initial `G28` home, **before** the model's own
first-layer/leveling G-code. Purpose: put the mechanism in a known state at
the start of every job, independent of whatever state it was left in after
the previous ejection.

```gcode
G28

; --- V2.93 MQTT sentinel: RESET (arm MQTT auto-trigger) ---
M104 S1                ; FL_S2 RESET sentinel (arm MQTT via nozzle_target_temper=1)

; --- RESET: 4 quick taps (within 3 seconds) ---
G1 Z255 F6000     ; Tap 1 - press
G4 P150
G1 Z243 F3000    ; Release
G4 P250
G1 Z255 F3000    ; Tap 2 - press
G4 P150
G1 Z243 F3000    ; Release
G4 P250
G1 Z255 F3000    ; Tap 3 - press
G4 P150
G1 Z243 F3000    ; Release
G4 P250
G1 Z255 F3000    ; Tap 4 - press
G4 P150
G1 Z243 F3000    ; Release

; Wait for reset sequence (bender returns home ~7s)
G4 P1000         ; Wait for reset complete

; --- TRIGGER 0: Long tap (3-4s) + Short tap ---

G1 Z255 F3000
M400
G4 P3500
G1 Z243 F3000    ; Release switch
G4 P500          ; Wait 500ms

G1 Z255 F3000    ; Short tap - quick press
G4 P200          ; Brief contact
G1 Z20 F3000    ; Release switch
```

Gesture shape: **4 quick taps (~150ms press / 250ms gap) → 1s settle → 1 long
press (~3.5s) → 500ms gap → 1 short tap (~200ms)**. The last release goes to
`Z20`, not `Z243`/`Z220` — worth double-checking against your own hardware's
neutral position rather than copying blindly.

> **Note:** the file's own comment says the reset takes "~7s" but the coded
> wait after the 4 taps is only `G4 P1000` (1s). Either the mechanism resets
> faster than the comment claims, or there's slack elsewhere (the TRIGGER 0
> long press) that absorbs the difference. Confirm on your own board before
> relying on the 1s figure.

---

## 4. ⚠️ The "FL NATURAL COOLDOWN" block — do not copy the placement

Appears a little further into the **start** sequence, still before the
model's nozzle-load/first-layer G-code:

```gcode
; ================ FL NATURAL COOLDOWN ================
; Hold in the closed chamber for 120 min before the door opens.
; Fans off so the part cools evenly instead of from one side — ASA, ABS
; and PC warp and split when cooled fast while still stuck to the plate.
M106 S0          ; part cooling fan off
M106 P2 S0       ; auxiliary fan off
M106 P3 S0       ; chamber fan off
G4 S30
G4 S30
... (240x total in the double-loop evidence file; the single-loop file matches this count per loop)
; ================ FL NATURAL COOLDOWN END (120 min) ================
```

This is exactly the defect written up in [../FL_S2_INCIDENT.md](../FL_S2_INCIDENT.md):
the block's own comment describes **post-print** behavior ("before the door
opens"), but it's spliced into the **pre-print** start sequence, heaters on,
fans off, for two hours. It reproduces in this single-loop file too — it
isn't specific to the double-loop case.

**If you want a real natural-cooldown hold, build it as its own stage gated
on bed temperature at the actual end of the print** — see the `M190 S26`
loop in §6, which *is* correctly placed. Don't lift this block's position;
only reuse the fan-off pattern (`M106 S0` / `M106 P2 S0` / `M106 P3 S0`) if
you need it, and remember `P2` = auxiliary, `P3` = exhaust/chamber on the
P2S (see [../gcode-snippets/README.md](../gcode-snippets/README.md)).

---

## 5. Nozzle-prep / bed-leveling swap (start sequence, minor)

Around the model's normal `G29.1` bed-mesh-compensation and nozzle-prime
lines, the processed file swaps in different values and a different prime
routine:

```gcode
G29.1 Z+0.00 ; for Textured PEI Plate
M109 S220
M975 S1
G90
M83
T1000

G92 E0
G1 E50 F200
M400
G1 X100 F21000
```

versus the stock slice's `G29.1 Z0.03` + a `G130`-based wipe-line prime.
This looks like app-level tuning (Z-offset choice, a simpler prime) rather
than anything the FarmBoard reacts to — no sentinel or tap pattern here.
`M975` and `T1000` meanings aren't confirmed against Bambu's command
reference; treat as unconfirmed and don't assume you need them unless you're
deliberately replicating the app's leveling behavior. Probably safe to leave
your slicer's stock version in place unless you hit a specific leveling
problem.

---

## 6. End-of-print: T1 → bed cooldown → T2 → sweep → safety → T3

This is the part worth replicating — it's the actual ejection cycle, and
(unlike §4) it's correctly positioned after the print's own end G-code.

### 6a. T1 sentinel + TRIGGER 1 (fan on, door open)

```gcode
; --- V2.93 MQTT sentinel: T1 (last-layer done) ---
M104 S2                ; FL_S2 T1 sentinel (open door + fan via nozzle_target_temper=2)

; --- TRIGGER 1: Long press (4-6 seconds) - Fan ON + Door Open ---
G1 Z243 F3000    ; Go to position
M400
G1 Z255 F3000       ; Press switch (slow = ~5s contact)
M400
G4 S5
M400
G1 Z243 F3000    ; Release switch
; Fan stays ON, door is opening
```

### 6b. Bed-temperature-gated cooldown (the *correct* cooldown)

```gcode
;Cooldown Start
M190 S26
M190 S26
... (repeated; 60 in this evidence file)
;Cooldown End
M140 S0 ; turn off bed
M104 S0 ; turn off hotend
```

`M190 Sxx` blocks until the bed reaches the target temperature — repeating
it is presumably a slicer-template artifact (or a workaround for something
re-issuing the wait), not literally 60 independent waits. If you write this
by hand, **one `M190 S<target>` should do the same job** — worth testing
rather than copying the repetition. `<target>` here is 26, matching the
temperature-based cooldown option mentioned in the incident report.

### 6c. T2 sentinel + TRIGGER 2 (start bending)

```gcode
; --- V2.93 MQTT sentinel: T2 (cool-done) ---
M104 S3                ; FL_S2 T2 sentinel (start bending via nozzle_target_temper=3)

; --- TRIGGER 2: Triple tap - Start bending ---
G4 P500
G1 Z255 F1000    ; Tap 1
G4 P150
G1 Z243 F3000
G4 P300
G1 Z255 F1000    ; Tap 2
G4 P150
G1 Z243 F3000
G4 P300
G1 Z255 F1000    ; Tap 3
G4 P150
G1 Z243 F3000

G4 P6000         ; Wait for count window to expire

; --- Wait for bending cycles ---
; 5 cycles x ~16s each = ~80 seconds
; Adjust based on your configured cycle count
G4 P85000        ; Wait for bending complete
```

Per the repo's own README, the bender is physically removed on this build
(it propped the bed open below 30 °C, replaced with an engineering plate) —
so this trigger is likely **not applicable to the current hardware**.
Documented here for completeness / in case the bender is reinstalled later.
The `5 cycles × ~16s` figure is explicitly a guess in the source comment —
if you ever re-enable the bender, verify the real cycle time instead of
trusting `G4 P85000`.

### 6d. Sweep / push section

Marked with `@fl:section:start "p2s.clear.sweep"` / `@fl:section:end` —
these look like the FarmLoop app's own template markers (probably consumed
by the app when re-processing a file, not by the printer or FarmBoard). Two
passes at different speeds, same path shape:

```gcode
; @fl:section:start "p2s.clear.sweep"
;============================= PUSH SECTION =============================
; @fl:replace next 1 "clear-height.smart-default"
G1 Z160.00 F10000
M400

; -------- central sweeps (2x) --------
G1 X125 F3000
G1 Y250 F3000
G1 Y0   F3000
G1 Y250 F3000
G1 Y0   F3000

; -------- extended right-to-left rake --------
; far right (X220), sweep back->front, step left 30mm each pass
G1 Y250 F3000
G1 X220 F3000
G1 Y0   F3000
G1 Y250 F3000
G1 X190 F3000
G1 Y0   F3000
G1 Y250 F3000
G1 X160 F3000
G1 Y0   F3000
G1 Y250 F3000
G1 X130 F3000
G1 Y0   F3000
G1 Y250 F3000
G1 X100 F3000
G1 Y0   F3000
G1 Y250 F3000
G1 X70  F3000
G1 Y0   F3000
G1 Y250 F3000
G1 X30  F3000
G1 Y0   F3000

G1 X220 F3000
M400

G1 Z160.00 F12000 ; second pass, faster
M400

; same rake pattern repeated at F12000
G1 Y250 F12000
G1 X220 F12000
G1 Y0   F12000
G1 Y250 F12000
G1 X190 F12000
G1 Y0   F12000
G1 Y250 F12000
G1 X160 F12000
G1 Y0   F12000
G1 Y250 F12000
G1 X130 F12000
G1 Y0   F12000
G1 Y250 F12000
G1 X100 F12000
G1 Y0   F12000
G1 Y250 F12000
G1 X70  F12000
G1 Y0   F12000
G1 Y250 F12000
G1 X30  F12000
G1 Y0   F12000
;===============================  END SECTION  =============================

M73 P74 R2
G1 X65 Y245 F12000     ; move to safe corner before parking
G1 Y265 F3000          ; final park at rear edge (idle position)
```

`Z160.00` is the sweep height (`@fl:replace next 1 "clear-height.smart-default"`
suggests the app computes this per-model from part height). Per
[../hardware-setup/README.md](../hardware-setup/README.md), if the sweep
misses parts or runs into them, the generated height math may be assuming
the nozzle tip and pusher contact face are coplanar when they aren't on your
build — measure that gap with the printer idle before trusting this number.

### 6e. Safety check trigger + T3 (final door close)

```gcode
; --- V2.93 MQTT sentinel: Safety (push-done) ---
M104 S4                ; FL_S2 safety sentinel (run safety check via nozzle_target_temper=4)

; --- TRIGGER SAFETY CHECK: Double tap ---
G1 Z243 F3000    ; Go to position
M400
G1 Z255 F1000    ; Tap 1
G4 P150
G1 Z243 F3000
G4 P300
G1 Z255 F1000    ; Tap 2
G4 S5
G1 Z243 F3000

; --- Wait for safety check (5-step sequence) ---
; Bender extend(7s) + retract(7s) + extend(7s) + door open(8s) + door close(8s) = ~37s
G4 P20000        ; Wait for safety check

; --- V2.93 MQTT sentinel: T3 (push-done, door close) ---
M104 S5                ; FL_S2 T3 sentinel (final door close via nozzle_target_temper=5)

; @fl:section:end "p2s.clear.sweep"
; @fl:section:start "p2s.stage2.trigger3"
; --- TRIGGER 3: Long press (4-6 seconds) - Final door close ---
G1 Z255 F3000
M400       ; Press switch (slow = ~5s contact)
G4 S5
M400
G1 Z220 F3000    ; Release switch
; @fl:section:end "p2s.stage2.trigger3"
```

Note the comment says the safety sequence takes ~37s but the coded wait
(`G4 P20000`) is only 20s — same kind of comment/code mismatch as §3.
Verify against real hardware timing rather than trusting either number
outright, and pad the dwell if your board consistently needs longer.

### 6f. Tail: fans off, motor current restore

```gcode
M106 S0 ; turn off fan
M106 P2 S0 ; turn off remote part cooling fan
M106 P3 S0 ; turn off chamber cooling fan

M400 ; wait all motion done
M17 S
M17 Z0.4 ; lower z motor current to reduce impact if there is something in the bottom

M400 P100
M17 R ; restore z current

M220 S100  ; Reset feedrate magnitude
M201.2 K1.0 ; Reset acc magnitude
M73.2   R1.0 ;Reset left time magnitude
M1002 set_gcode_claim_speed_level : 0

M17 X0.8 Y0.8 Z0.5 ; lower motor current to 45% power
```

The `M17 S` / `M17 Z0.4` / `M400 P100` / `M17 R` block (lower Z current,
pause, restore) is stock Bambu end G-code — kept as-is, just moved to after
the ejection cycle instead of being the very last thing that runs. The
processed file also **drops** the stock sound sequence (`M1006 ...`) and the
air-purification block (`M622`/`M623`) that the plain slice has — decide
deliberately whether you want those back; nothing here suggests the
FarmBoard needs them gone, they may just not have been carried over.

---

## 7. Consolidated timing reference

| Stage | Tap pattern | Post-trigger wait |
|---|---|---|
| RESET | 4x quick tap (150ms press / 250ms gap) | `G4 P1000` (1s) |
| TRIGGER 0 | 1 long press (~3.5s) + 1 short tap (~200ms) | none coded |
| TRIGGER 1 (fan+door) | 1 long press (~5s) | none coded before bed cooldown |
| Bed cooldown | — | `M190 S26` until bed ≤ 26 °C |
| TRIGGER 2 (bend) | 3x tap (~1s hold, ~300ms gap) | `G4 P6000` + `G4 P85000` (~91s total, tune to your bend-cycle count) |
| Safety check | 2x tap (last tap held 5s) | `G4 P20000` (20s; comment implies ~37s — verify) |
| TRIGGER 3 (door close) | 1 long press (~5s) | none coded |

---

## 8. Before writing your own injection block

- Re-run the diff yourself against a current export before trusting any
  value above — app version, firmware version, and your own Detachment
  Tuning settings (push height, cooldown target) all change the generated
  numbers:
  ```bash
  diff raw/Metadata/plate_1.gcode fl/Metadata/plate_1.gcode | less
  ```
- Don't lift the §4 cooldown block's *position* — only its fan-off pattern
  if you need one, placed at the real end of print.
- Confirm the sweep height (`Z160.00` here) against your own nozzle/pusher
  gap, not this model's number.
- If the bender is out of your build (per the main [README.md](../README.md)),
  TRIGGER 2 and the safety check's bender-extend/retract timing likely don't
  apply — you may only need TRIGGER 1 (door open), the bed cooldown, and a
  door-close trigger.
- Test each stage watching the machine, one trigger at a time, before
  trusting a full unattended run — see [../FL_S2_INCIDENT.md](../FL_S2_INCIDENT.md#how-to-check-your-own-files-before-running-them).

---

## 9. Options for the ejection block

This build differs from what the FarmLoop app assumes: an **engineering
plate** (parts self-release below ~30 °C, no bending needed) with the
**bender physically removed** (it propped the chamber open), leaving only
the FarmBoard **door** and the toolhead **pusher**. [`start-gcode-p2s.gcode`](start-gcode-p2s.gcode)
and [`end-gcode-p2s.gcode`](end-gcode-p2s.gcode) in this folder implement
the recommended option below; the alternatives are documented here in case
your setup differs.

### Event-order options

| | Option | Order of events | Pros | Cons / risks |
|---|---|---|---|---|
| **A (used)** | Cool-closed, then open | print end → fans off/aux+exhaust on → `M190 S<release>` → buffer dwell → T1 door open → sweep → T3 door close → tail | Parts release before anything moves; chamber heat stays in the box | Slower than B; needs `M190` to actually block on cooling — verify on your firmware |
| B | FarmLoop's order: open first, cool with door open | print end → T1 door open+fan → `M190` → sweep → T3 close | Fastest cooldown | Dumps chamber heat/fumes into the room while cooling |
| C | Sentinel-only (no Z taps) | Same as A, minus every `G1 Z243/Z255` block | Simplest, no Z-axis hammering | Dead if MQTT/Digital mode drops — not used here, kept as a fallback |
| D | No FarmBoard | Door left open/removed; `M190` → sweep → park | Zero dependency on the board | Chamber open permanently; PLA/PETG only |
| E | Material-dependent A/B | Two end blocks, toggled per queue item in Bambuddy | Best of A and B per material | Two snippets to keep in sync |

### Sweep sub-options

- **Per-model height, `{max_layer_z} − 10`** — used. This is FarmLoop's
  own default: its Detachment Tuning page says "Push height is
  automatically calculated as the maximum part height minus 10 mm", and
  the evidence file (a 170.00 mm part, `max_z_height` in its header) was
  swept at `Z160.00`. Bambuddy resolves `{max_layer_z}` at dispatch; the
  `−10` is a relative `G91` move. **Not safe below ~12 mm part height**
  — see the `SWEEP_MIN` note in the snippet. (The stock P2S end G-code
  runs `M211 Z1`, so at this point a negative Z clamps at 0 rather than
  driving the bed into the nozzle — but the toolhead then drags across
  the plate, so the rule stands.)
- **Dual-speed passes** — slow (`F3000`) first, fast (`F12000`) second.
  The source file's own pattern, kept as-is.
- ~~Dual-height rake~~ — dropped after the first live run. On a 15 mm
  part the formula already puts the pusher 5 mm off the plate; there is
  no meaningful lower pass, and without a measured pusher offset a lower
  pass is a plate-crash risk.
- Not used, but worth knowing about: a slow "nudge" pass at low Z *before*
  the real sweep to break loose any parts still stuck; sweeping the plate
  perimeter before the central rake, for plates packed to the edges.

### Release-gate sub-options (A uses the first)

- `M190 S<target>` (block until bed reaches target) + a fixed `G4` buffer
  dwell — used here, since bed temperature is the only signal available
  and the plate/part interface lags the sensor.
- Fixed time only, no temperature check — simpler, but ignores room
  temperature swings.
- Temperature gate plus a nudge pass (see above) before the real sweep.

### Open questions carried into the snippets

1. ~~Where Bambuddy inserts the end block.~~ **Resolved — see section 10.**
2. ~~Whether the FarmBoard needs T2 (`S3`) / Safety (`S4`) sentinels before
   it'll accept T3 (`S5`).~~ **Resolved on the first live run (2026-09-20):
   it doesn't.** The door closed on T3 with S3/S4 never sent, so
   `end-gcode-p2s.gcode` skips both with no shim.

---

## 10. How Bambuddy actually inserts these snippets

Confirmed by reading Bambuddy's source directly (`maziggy/bambuddy`, commit
`9e9c08b`, main, 2026-09-17) — this replaces guesswork with the real
mechanism, and fills the TODO in
[../software-setup/README.md#4-wire-it-into-bambuddy](../software-setup/README.md#4-wire-it-into-bambuddy).

**Injection happens server-side, in Python, at print-dispatch time — not on
the printer and not in the slicer.** When a queue item has
`gcode_injection = True`, `PrintScheduler._start_print()`
(`backend/app/services/print_scheduler.py`) calls
`inject_gcode_into_3mf()` (`backend/app/utils/threemf_tools.py`), which:

1. Opens the `.gcode.3mf` (a zip), and edits the plate's `.gcode` text
   in-memory.
2. **Start snippet** (what you paste into Settings → Workflow → G-code
   Injection → start_gcode) is inserted immediately **before** the line
   `; MACHINE_START_GCODE_END`. That marker sits at the bottom of the
   printer's own startup block — bed heat, homing, nozzle prime are already
   done by the time your snippet runs. This is why
   [`start-gcode-p2s.gcode`](start-gcode-p2s.gcode) has **no leading
   `G28`** — it would be redundant.
3. **End snippet** is inserted immediately **before** `; EXECUTABLE_BLOCK_END`.
   Bambu firmware (confirmed on a P1S, per the injector's own code comments)
   ignores G-code placed *after* that marker — so your end snippet runs
   *inside* the executable block, but **after the printer's own complete
   machine-end sequence**, which this repo's own plain-slice evidence file
   ends with `M18` (steppers fully de-energized). This is why
   [`end-gcode-p2s.gcode`](end-gcode-p2s.gcode) now starts with an explicit
   **`M17`** before any `G1 Z` move — without it, the first tap gesture
   would be commanding a disabled stepper.
4. Recomputes the `Metadata/plate_N.gcode.md5` sidecar automatically. You
   don't need to handle this yourself — it's only relevant if you ever
   write your own injector outside Bambuddy.
5. Writes a temp copy and uploads that; **the original library/archive
   file is never modified.**

If either marker is missing from a file (older export, non-Bambu slicer),
Bambuddy falls back to prepending (start) or appending at EOF (end) instead
— worth knowing if a future firmware/slicer update changes the template.

**Other behavior worth knowing:**

- **Injection failure is silent.** Any exception, or a `None` result, logs
  a warning server-side and the **original, un-injected file prints
  instead** — nothing on the printer itself will tell you your snippet
  didn't run. Check Bambuddy's logs if the ejection cycle doesn't fire.
- **Snippets are keyed by printer model**, so a farm with mixed printer
  models can carry different snippets per model in the same Settings JSON.
- **Placeholder substitution exists**: `{max_layer_z}` / `{max_print_height}`
  resolve to the model's tallest point (Bambu's `max_z_height` header
  field), `{total_layers}` to `total_layer_number`. Substitution is
  literal text replacement only — no arithmetic — so you can't write
  `{max_layer_z - 10}`. The workaround `end-gcode-p2s.gcode` uses:
  `G1 Z{max_layer_z}` then `G91` / `G1 Z-10` / `G90`. **Confirmed present
  in the 1.2.5.5 tag** (fetched `backend/app/utils/threemf_tools.py` at
  that tag: `_substitute_placeholders`, the `max_layer_z` alias, both
  markers and the MD5 recompute are all there), not just on main.
- If a placeholder is unknown it is left as literal text with only a
  server-side warning, so `G1 Z{max_layer_z}` would reach the printer
  verbatim. Bambu firmware should reject the malformed Z and not move,
  and the following relative `Z-10` then runs from wherever the bed is —
  harmless at the post-tap height, but the sweep would run at the wrong
  Z. If parts are ever left behind, check Bambuddy's logs for that
  warning first.
- Only one plate is targeted (the one selected, or else the lowest-numbered
  `.gcode` member) — irrelevant for single-plate farm prints, but worth
  knowing if you ever queue multi-plate files.

---

## 11. First live run (2026-09-20) and the M190 test

Run with `end-gcode-p2s.gcode` as it stood before this section, on a
~15 mm part (75 layers × 0.2 mm):

| Observation | Meaning | Change made |
|---|---|---|
| Door closed at the end | T3 works without S3/S4 | shim removed (§9 q2) |
| Sweep "way too high" | fixed `Z160` was from a 170 mm part | `{max_layer_z} − 10` (§9) |
| Smell in the room during cooldown | aux fan (`P2`) recirculating fumes | `M106 P2 S0`; exhaust `P3` kept |
| Screen showed "cooling until 28 °C", door opened — not clear when | `M190 S28` was *recognised* as a bed wait, but unknown whether it released at 28 °C or timed out earlier (the `G4 S120` right after it hides the moment) | isolate it with the test below |

Why the timing is worth one dedicated run: in Marlin lineage `M190 S`
waits only while *heating*; `M190 R` waits in both directions. FarmLoop's
own file repeats `M190 S26` sixty times, which smells like a per-call
timeout being worked around. Bambu's real behaviour is unknown.

> **`M190 R` is off the table.** Tried on 2026-09-20 (injection confirmed
> working — the start taps ran): the printer raised *"temperature of the
> heated bed exceeds the limit and automatically adjusts to the limit
> temperature"*, then reported Finished a few minutes later with no door
> movement. That text is **HMS 0300-0100-0003-0008**, whose documented
> cause is "the heatbed temperature set in G-code exceeds the limit; the
> printer adjusts to the maximum allowable temperature" — so the `R`
> form was parsed as a target *above* the bed maximum and the bed was
> commanded up, not down. On the X1C forum thread `M190 R` is reported as
> "does not work… times out after maybe 10 minutes… gives up around 45 °C"
> (arthor, 2024). Treat it as a heater-on hazard on this firmware.

**Test:** [`end-gcode-test-m190.gcode`](end-gcode-test-m190.gcode). Paste
it as the END snippet in place of the production one, queue a tiny
1-layer print (no sweep, no door, no taps — a leftover part is fine),
and watch the bed temperature on the printer screen. Three `M190 S28`
run back to back; after each one the **part-cooling fan spins for 3 s
and the toolhead jogs 30 mm in X and back** — audible and visible, no
Z, no door. Note the bed temperature and clock time at every signal and
when Finished appears:

| Signals… | Verdict | Production fix |
|---|---|---|
| once at ~28 °C after a real wait, then twice more within seconds | `M190 S` blocks until cool | keep the single `M190 S28` — done |
| every N seconds/minutes, bed still hot each time | `M190 S` has a per-call timeout of N | repeat `M190 S28` ⌈cooldown ⁄ N⌉ times (FarmLoop's 60× now makes sense) |
| within seconds of the last layer, all three in a row | `M190 S` ignores cooling | fixed `G4 S<seconds>` sized to a cooldown you time by hand |

Even if you miss the signals, the bed temperature when the screen shows
**Finished** settles most of it: ~28 °C means it blocks until cool;
clearly hotter means it timed out three times over.

> The first version of this test toggled the "logo lamp" (`M960 S5`)
> because the stock P2S start G-code uses it. That lamp is an X1-series
> part; the P2S has nothing visible to switch, and nothing was seen on
> the 2026-09-22 run. That run still produced a result: the bed was 42 °C
> at the last layer and the screen still read "cooling to 28 °C" minutes
> later, so `M190 S28` **does hold on cooling** at least that long —
> what's left is whether it holds all the way to 28 °C.

**What the community says about `M190 S` on cooling** (all X1/P1-era
reports; none P2S-specific, which is why our own test matters):

- the_Raz (X1C, 2023): "Bambu seem to use M190 S for cooling too: I've
  seen it (unnecessarily) wait for cooling after I replaced the smooth
  PEI to the cold plate between prints."
- NVNDO (2024), working auto-eject end G-code: `M140 S0 ; For some reason
  you need to set the bed temp again before` → `M190 S30 ; wait for bed
  to be cold` → `G04 S300` → push. Note the `M140 S0` *first* — our
  snippet already does that.
- julie777 (2024): set `M190 S40`, "code execution does not continue
  until the bed temp reaches 33C" — a ~7 °C **undershoot**. If the P2S
  does the same, a 28 °C target may need ~21 °C bed, unreachable in a
  warm room. `RELEASE_TEMP` guidance in the snippet header covers this.
- ProtoSpyre (2024): a soft alarm "bed temperature abnormal, exceeds
  maximum temperature" while the bed sits above a low target. Not seen
  on our runs with `S28` (only with `R28`), but worth recognising.
- Alternatives people use instead: `M140 S<t>` + `G4 P60000` ×10 stepped
  down (3DTech), or `M400 S600` + `M140 S<t>` steps (JonRaymond). Both
  are time-based; `M190 S` repeated N× (FarmLoop's 60×) is the only
  temperature-based form in the wild.

---

## 12. Line-by-line verification (2026-09-22)

Sources: **stock** = the P2S start/end templates (2026/05/18) embedded in
the evidence file's header; **atlas** = the community Bambu G-code atlas
(georgebashi), with its own confidence marks; **FL** = the FarmLoop app's
output in the evidence file; **vendor** = 3D Farmers help center;
**run** = observed on this printer.

| Line(s) | Purpose | Verified by | Status |
|---|---|---|---|
| `M17` (bare) | re-enable steppers after stock `M18` | atlas ✅ standard; stock end ends `M400` / `M18` | OK |
| `M106 S0` / `P3 S0` / `P10 S0` | part, chamber, left-aux fans off | atlas ✅ P-index table (P10 = P2S left aux); stock end uses all three | OK |
| `M145 P1` + `M106 P2 S255` | closed duct, recirculate through filter | stock end "air purification" J1 branch, byte-identical; ha-bambulab: mode 1 "uses chamber air sucked through a filter" | OK |
| `M145 P0` + `M106 P3 S255` (commented alt.) | cooling mode, vents | stock end J2 branch; ha-bambulab: mode 0 "air is pulled from the outside" | OK, smells |
| `M140 S0`, `M104 S0` | heaters off (again) | standard; NVNDO's "set the bed temp again before M190" | OK |
| `M190 S28` ×4 | wait for bed to cool | run: screen "cooling to 28 °C", held ≥ minutes at 42 °C; the_Raz, NVNDO, julie777 | **hold confirmed; finish temp / timeout / undershoot pending test** |
| `M190 R…` | — | run: HMS 0300-0100-0003-0008; arthor: times out ~10 min | **never use** |
| `G4 S120`, `G4 S12`, `G4 S5` | dwell, seconds | forum 666: `G4 S` seconds, `P` ms; FL uses both | OK |
| `M104 S2` / `M104 S5` | FarmBoard sentinels | FL comments "V2.93 MQTT sentinel"; run: door opened on S2, closed on S5 | OK on this board; **not vendor-documented** |
| `G1 Z243` / `Z255` / `Z220` presses | switch gestures | FL file; vendor gesture table (long press 4–8 s = door open / door close); printable_height 256 | OK; inert while Digital mode connected (vendor) |
| `G1 Z{max_layer_z}` + `G91 Z-10 G90` | sweep height = max part − 10 | FarmLoop UI text + evidence (170 → 160); Bambuddy 1.2.5.5 source has the alias | OK; **pusher contact not yet seen at this height** |
| sweep X/Y pattern | rake parts to the front | FL file verbatim; X/Y soft endstops off (stock never re-enables) so Y265 is legal | OK |
| `G91 Z30 G90` lift | clear leftover parts before park | our addition; Z soft endstop on (`M211 Z1`, stock end line 3) | OK |
| `M18` | steppers off | stock end's last command | OK |
| `M17 S / Z0.4 / R` bracket | (removed) | atlas: `M17 S` ❓ unknown; bracket only meaningful around a downward move | removed as no-op |
| `M960 S5` | (removed from test) | forum 666: "toolhead logo lamp"; run: nothing visible on P2S | removed |
| start: `M104 S1` + 4 taps + long+short | reset, close door | FL file; vendor: "four quick taps = emergency reset", "long press + short tap = close door, print begins"; soft endstops off here (`M211 X0 Y0 Z0` ×2 before marker) | OK |

> **Where the references disagree with the printer, the printer wins.**
> The atlas' thermal section states the P2S "has no M145 P1 (heating-mode
> routing)" and "no M141/M191 anywhere in P2S templates". The 2026/05/18
> P2S template embedded in this repo's evidence file contains both:
> `M145 P1 ; set airduct mode to heating mode for heating` (start, and
> the end G-code's air-purification J1 branch) and `M191 S0 ; wait for
> chamber temp` (start, cooling branch). The atlas was compiled from an
> older profile set. The ha-bambulab P2S issue independently describes
> mode 1 as "chamber air sucked through a filter", which is what the
> snippet relies on.

### Still needs confirmation on this printer

1. **`M190 S28` finish temperature** — does it release at 28, undershoot,
   or time out? The running/next `end-gcode-test-m190.gcode` answers it.
2. **Sweep contact** at `{max_layer_z} − 10` on a real part: the formula
   is the vendor's, but the pusher's face-to-nozzle offset on this
   toolhead has never been measured.
3. **Filter-mode cooldown time** with the door closed and only the aux
   fan recirculating — likely much slower than the vented run; if it's
   impractical, switch to the commented `M145 P0` alternative and accept
   the smell, or vent the room.
4. **Sentinel-only door open** — the one run without taps (the `R28` run)
   failed, but the HMS alarm confounds it. Not important while both
   mechanisms are in the file.
5. **`M145 P0` in the tail** — restores the stock end's final airduct
   state; harmless, but unverified that the next print's start G-code
   expects it (it sets its own mode anyway).

Put `end-gcode-p2s.gcode` back afterwards and carry the result into its
section 1.

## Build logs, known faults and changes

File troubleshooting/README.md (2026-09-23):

# Troubleshooting & status

Detailed, in-the-weeds notes for people actually building this. If you're just here to see how the farm is architected, the [root README](../README.md) covers that; this file is the deep dive.

## Status

| Area | State |
|---|---|
| Bambuddy on headless server | Working |
| OrcaSlicer sidecar | Working |
| Bambu Studio sidecar | **TODO:** confirm |
| Part detachment | Fixed with an engineering plate |
| FarmBoard MQTT connection | **TODO:** confirm |
| Door opening | **TODO:** confirm |
| Push sweep height | **TODO:** confirm |
| Cooldown timing | **TODO:** confirm |

## Troubleshooting

| Symptom | Likely cause / fix |
|---|---|
| `no configuration file provided` when starting the sidecars | You ran compose from the wrong folder. `cd bambuddy/slicer-api` first. |
| FarmBoard LED shows 4 long blinks | MQTT failed. Recheck IP and access code, and confirm LAN-only mode. |
| FarmBoard says "No printer configured" | Recheck the Printer Connection card. Also check that the printer's IP isn't on the same subnet as the board's own setup access point. **TODO:** confirm whether this was your cause. |
| Access code stopped working | It regenerates when LAN-only or Developer Mode is toggled. |
| Cycle doesn't fire | The `FL_S2_` file was renamed or re-saved. Re-process it in the app. |
| Bambu Studio shows "Stopped" for a good print | Display quirk of how it reads the G-code end. The board still completes its sequence. |
| Part bends loose but isn't ejected | Bending only detaches. The push sweep is what ejects. |
| Sweep passes above short parts | Nozzle-to-pusher offset. Measure it, then adjust. |
| Very long wait before the door opens | Stock end G-code cooldown, not your added block. |
| Printer freezes mid-print | Check for a full USB stick from video recordings. |
| Lift Mode greyed out | Not supported on the P2S. Use Push Mode. |
| Bambuddy unreachable from your phone | Firewall on the server (port 8001). |

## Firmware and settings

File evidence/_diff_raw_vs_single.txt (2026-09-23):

589a590,625
> G28
> 
> ; --- V2.93 MQTT sentinel: RESET (arm MQTT auto-trigger) ---
> M104 S1                ; FL_S2 RESET sentinel (arm MQTT via nozzle_target_temper=1)
> 
> ; --- RESET: 4 quick taps (within 3 seconds) ---
> G1 Z255 F6000     ; Tap 1 - press
> G4 P150
> G1 Z243 F3000    ; Release
> G4 P250
> G1 Z255 F3000    ; Tap 2 - press
> G4 P150
> G1 Z243 F3000    ; Release
> G4 P250
> G1 Z255 F3000    ; Tap 3 - press
> G4 P150
> G1 Z243 F3000    ; Release
> G4 P250
> G1 Z255 F3000    ; Tap 4 - press
> G4 P150
> G1 Z243 F3000    ; Release
> 
> ; Wait for reset sequence (bender returns home ~7s)
> G4 P1000         ; Wait for reset complete
> 
> ; --- TRIGGER 0: Long tap (3-4s) + Short tap ---
> 
> G1 Z255 F3000
> M400
> G4 P3500
> G1 Z243 F3000    ; Release switch
> G4 P500          ; Wait 500ms
> 
> G1 Z255 F3000    ; Short tap - quick press
> G4 P200          ; Brief contact
> G1 Z20 F3000    ; Release switch
684a721,970
> 
> ; ================ FL NATURAL COOLDOWN ================
> ; Hold in the closed chamber for 120 min before the door opens.
> ; Fans off so the part cools evenly instead of from one side — ASA, ABS
> ; and PC warp and split when cooled fast while still stuck to the plate.
> M106 S0          ; part cooling fan off
> M106 P2 S0       ; auxiliary fan off
> M106 P3 S0       ; chamber fan off
> G4 S30
> G4 S30
> G4 S30
> G4 S30
> G4 S30
> G4 S30
> G4 S30
> G4 S30
> G4 S30
> G4 S30
> G4 S30
> G4 S30
> G4 S30
> G4 S30
> G4 S30
> G4 S30
> G4 S30
> G4 S30
> G4 S30
> G4 S30
> G4 S30
> G4 S30
> G4 S30
> G4 S30
> G4 S30
> G4 S30
> G4 S30
> G4 S30
> G4 S30
> G4 S30
> G4 S30
> G4 S30
> G4 S30
> G4 S30
> G4 S30
> G4 S30
> G4 S30
> G4 S30
> G4 S30
> G4 S30
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
> ; ================ FL NATURAL COOLDOWN END (120 min) ================
> 
876,881c1162
< ;===== for Textured PEI Plate , lower the nozzle as the nozzle was touching topmost of the texture when homing ==
<   
<     
<       G29.1 Z0.03
<     
<   
---
> G29.1 Z+0.00 ; for Textured PEI Plate
882a1164
> M109 S220
884,901c1166,1179
< ;===== nozzle load line ===============================
< M1002 gcode_claim_action : 51
<   G29.2 S1 ; ensure z comp turn on
<   G90
<   M83
<   M400 P50
<   M500 D1
<   M400 S3
<   M109 S220
<   G0 X100 Y0 F24000
<   M400
<   ;G130 O0 X100 Y-0.4 Z0.8 F4.36536 L40 E20 D5
<   G130 O0 X100 Y-0.2 Z0.6 F4.36536 L40 E12 D4
<   G90
<   M83
<   G1 Z1
<   M400
< ;===== noozle load line end ===========================
---
> M975 S1
> G90
> M83
> T1000
> 
> G92 E0
> 
> G1 E50 F200
> 
> M400
> 
> G1 X100 F21000
> 
> M400
209587,209588c209865,209867
< M17 S
< M17 Z0.4 ; lower z motor current to reduce impact if there is something in the bottom
---
> M140 S0 ; turn off bed
> M104 S0 ; turn off hotend
> M106 P2 S255 ; turn on remote part cooling fan
209590,209593c209869,209870
<     
<         G1 Z174 F600
<         G1 Z172
<     
---
> ; --- V2.93 MQTT sentinel: T1 (last-layer done) ---
> M104 S2                ; FL_S2 T1 sentinel (open door + fan via nozzle_target_temper=2)
209595,209596c209872,209879
< M400 P100
< M17 R ; restore z current
---
> ; --- TRIGGER 1: Long press (4-6 seconds) - Fan ON + Door Open ---
> G1 Z243 F3000    ; Go to position
> M400
> G1 Z255 F3000       ; Press switch (slow = ~5s contact)
> M400
> G4 S5
> M400
> G1 Z243 F3000    ; Release switch
209597a209881
> ; Fan stays ON, door is opening
209599,209602c209883
< M220 S100  ; Reset feedrate magnitude
< M201.2 K1.0 ; Reset acc magnitude
< M73.2 R1.0 ;Reset left time magnitude
< M1002 set_gcode_claim_speed_level : 0
---
> ;Cooldown Start
209604,209605c209885,209946
< M1015.3 S0 ;disable clog detect
< M1015.4 S0 K0 ;disable air printing detect
---
> M190 S26
> M190 S26
> M190 S26
> M190 S26
> M190 S26
> M190 S26
> M190 S26
> M190 S26
> M190 S26
> M190 S26
> M190 S26
> M190 S26
> M190 S26
> M190 S26
> M190 S26
> M190 S26
> M190 S26
> M190 S26
> M190 S26
> M190 S26
> M190 S26
> M190 S26
> M190 S26
> M190 S26
> M190 S26
> M190 S26
> M190 S26
> M190 S26
> M190 S26
> M190 S26
> M190 S26
> M190 S26
> M190 S26
> M190 S26
> M190 S26
> M190 S26
> M190 S26
> M190 S26
> M190 S26
> M190 S26
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
< ;=====printer finish air purification=========
< M622.1 S0
< M1002 judge_flag print_finish_air_filt_flag
---
> ;Cooldown End
209611,209617c209950
< M622 J1
< M1002 gcode_claim_action : 66
< M145 P1
< M106 P2 S255
< M400 S180
< M106 P2 S0
< M623
---
> M140 S0 ; turn off bed
209619,209626c209952,210026
< M622 J2
< M1002 gcode_claim_action : 66
< M145 P0
< M106 P3 S255
< M400 S180
< M106 P3 S0
< M623
< ;=====printer finish air purification=========
---
> M104 S0 ; turn off hotend
> 
> ; --- V2.93 MQTT sentinel: T2 (cool-done) ---
> M104 S3                ; FL_S2 T2 sentinel (start bending via nozzle_target_temper=3)
> 
> ; --- TRIGGER 2: Triple tap - Start bending ---
> G4 P500
> G1 Z255 F1000    ; Tap 1
> G4 P150
> G1 Z243 F3000
> G4 P300
> G1 Z255 F1000    ; Tap 2
> G4 P150
> G1 Z243 F3000
> G4 P300
> G1 Z255 F1000    ; Tap 3
> G4 P150
> G1 Z243 F3000
>
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
